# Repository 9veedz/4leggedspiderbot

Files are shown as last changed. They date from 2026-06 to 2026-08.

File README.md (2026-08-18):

# ESP32 Quadruped Spider Robot

> Built largely through vibe coding, iterating with an AI assistant rather than writing every line from scratch. Logic has been tested where possible, but review the code yourself before trusting it on real hardware, especially the servo angle limits.

A 4-legged (12-servo) walking robot controlled by an ESP32, with a built-in WiFi access point and web-based control interface for live tuning, calibration, and gait control — no app required, just a browser.

>  **This project is sponsored by [PCBWay](https://www.pcbway.com)!**

Many thanks to PCBWay for sponsoring this project with high-quality PCBs. As a small hobby project with no real following or funding, being approached by PCBWay for sponsorship genuinely means a lot. I'm truly grateful for the support — it's what made getting real boards in my hands possible. More details in the [sponsor section](#sponsor--pcbway) below.

> ⚠️ This is an ongoing hobby project — still actively being developed and subject to changes.
## Demo

**Walking gait**

Spider Robot Walking (https://youtube.com/shorts/MwilIVm9K1Y)

**Body roll & pitch control**

Spider Robot Body Roll and Pitch (https://youtube.com/shorts/5wvZWfhv1cs)
> The robot moves significantly more fluidly than the videos suggest — the choppy appearance is purely down to the low frame rate of the recording. The inverse kinematics system interpolates each leg smoothly in real time; what you're seeing is a capture artifact, not the actual motion quality.

## Features

- **Inverse kinematics leg control** — each leg independently computes coxa/femur/tibia servo angles from X/Y/Z target positions.
- **Live web UI** — connects directly to the ESP32's own WiFi access point and serves a mobile-friendly control panel over WebSocket (`/ws`) with a captive portal so it opens automatically on connect.
- **Body posture control** — adjustable body height, width, stride length, pitch, and roll, with automatic tilt trim calculation per leg.
- **Walking gaits** — forward and reverse walking gaits using a diagonal-pair stepping pattern (lift → stride → push → recover).
- **Per-leg calibration** — manual servo angle control, configurable min/max safety limits, and offset trims per joint (coxa/femur/tibia), saved persistently to flash (ESP32 NVS/Preferences).
- **Per-leg power control** — individually or globally power legs on/off (releases servo PWM signal) for safe handling or storage.
- **Robot state machine** — `SIT`, `STAND`, `FORWARD`, `REVERSE` states drive automatic transitions between resting and walking behavior.

## Hardware

- ESP32 development board
- PCA9685 16-channel PWM/servo driver (I2C)
- 12x servos (3 per leg: coxa, femur, tibia)
- 4-leg chassis, with legs 1 and 2 mirrored relative to legs 0 and 3
- 3D-printed body: [Thingiverse Thing #2204279](https://www.thingiverse.com/thing:2204279), based on the design from [Instructables: DIY Spider Robot / Quad Robot / Quadruped](https://www.instructables.com/DIY-Spider-RobotQuad-robot-Quadruped/)

> **Important — before assembling the legs onto the 3D-printed body:** power each servo individually and set it to **90 degrees** *before* mounting the horn and locking the leg segments onto the printed body. The codebase has calls toward a `spiderCalibrate()` / `calibrateServos()` path, but it is not a complete, working calibration setup as-is — don't rely on it out of the box. Manually centering each servo to 90° before assembly (e.g. with a basic standalone test sketch) is the safer approach until calibration is properly wired up. The IK math and default offsets (`offC`/`offF`/`offT` = 90) assume each joint's mechanical zero/center point lines up with 90° on the servo. If a horn is attached and the leg geometry locked in at the wrong angle, the leg will be physically offset from where the code thinks it is, and you'll fight it with calibration offsets indefinitely instead of starting from a clean baseline.

| Leg | Coxa Pin | Femur Pin | Tibia Pin | Position | Mirrored |
| --- | --- | --- | --- | --- | --- |
| 0 | 0 | 1 | 2 | Front-left  | No |
| 1 | 3 | 4 | 5 | Front-right | Yes |
| 2 | 6 | 7 | 8 | Back-left | Yes |
| 3 | 9 | 10 | 11 | Back-right  | No |

### Leg Segment Lengths

Each leg has three segments, defined as constants in `SpiderLeg.cpp` and used directly in the inverse kinematics calculations:

| Segment | Joint | Length (mm) | Description |
| --- | ----- | --- | --- |
| L1 | Coxa  | 27.5 | Hip joint offset, rotates leg in X/Y plane |
| L2 | Femur | 55.0 | Upper leg segment |
| L3 | Tibia | 77.5 | Lower leg segment, reaches the ground |

These are physical measurements of the chassis/leg hardware, used by `calculateIK()` to solve for coxa, femur, and tibia joint angles from a target X/Y/Z foot position. If you build this on different hardware, these three constants are the first thing to update to match your own leg dimensions.

## Project Structure

This is an Arduino IDE sketch. Arduino IDE requires a `.ino` file matching the sketch folder name, but all real logic lives in standard `.cpp`/`.h` files, which the IDE compiles automatically alongside it.

```
code/
├── SpiderRobot.ino     # Entry point: setup() / loop()
├── Spider.h / .cpp     # High-level robot behavior: stand, sit, walk, calibrate
├── SpiderLeg.h / .cpp  # Per-leg inverse kinematics & servo output
├── Robotstate.h / .cpp # Shared global state, persistence (flash/NVS)
├── Spiderserver.h / .cpp # WiFi AP, captive portal, WebSocket server
└── Webpage.h           # Embedded HTML/CSS/JS control panel (served from flash)
```

## Code Structure Notes

Each leg is its own object with its own pins and position, and handles its own mirroring internally. `Spider` just tells legs where to go. Makes gait code easier to read, and adding more legs later is mostly just adding more leg objects.

## Getting Started

1. Open `SpiderRobot.ino` in Arduino IDE.
2. Install required libraries via Library Manager:
  - `Adafruit PWM Servo Driver Library`
  - `ESPAsyncWebServer`
  - `AsyncTCP`
  - `ArduinoJson`
  - `DNSServer` (bundled with ESP32 core)
3. Select your ESP32 board under **Tools > Board**.
4. Wire the PCA9685 to the ESP32 via I2C and connect all 12 servos.
5. Flash the sketch.
6. On boot, the ESP32 creates a WiFi access point:
  - **SSID:** `ESP32_Spider`
  - **Password:** `12345678`
7. Connect to that network from a phone or laptop. A captive portal should prompt you to open the control page automatically (or browse to `192.168.4.1` manually).

> **Note:** The AP credentials are currently hardcoded in `Spiderserver.cpp`. Change them before deploying anywhere you don't fully control.

## Using the Web Interface

- **Robot Motion State** — switch between Sit / Stand / Forward / Reverse.
- **Body / Global** — tune body height, width, stride, pitch, and roll in real time.
- **Leg Select & Power** — choose which leg's parameters you're editing, and power individual or all legs on/off.
- **Geometry** — per-leg W/H/L trim offsets.
- **Servo Offsets** — per-joint calibration offsets (coxa/femur/tibia).
- **Servo Angle Control** — manually drive a joint to a specific angle (calibration mode).
- **Servo Min/Max** — set safe angle limits per joint to protect hardware.
- **Save to Flash** — persists all current settings to the ESP32's non-volatile storage.
- **Reload/Reset Defaults** — restores factory default values.

All changes apply live over WebSocket; no page reloads are needed.

## Understanding the Inverse Kinematics

If you want to understand how the leg IK math works before diving into `SpiderLeg.cpp`, this video explains it well:

📺 [Inverse Kinematics for a 3-segment leg — YouTube](https://youtu.be/HjmIOKSp7v4?si=qGuz0ecaw_1wg7XF)

## How to Swap in Your Own Control Scheme

The main robot logic lives in `SpiderLeg`, `Spider`, and `Robotstate` — those are the brains. `Spiderserver` and `Webpage` are just how *this* project talks to the robot over WiFi/WebSocket. You can rip those out entirely and replace them with whatever you want — a Bluetooth remote, an RC receiver, a gamepad, a serial interface — as long as you write to the same variables in `Robotstate`.

Everything the robot responds to is exposed as simple global variables you can read or write from anywhere:

**Body / Posture**

| Variable | Type | Description |
| --- | --- | --- |
| `bodyHeight` | `float` | Overall body height offset |
| `bodyWidth`  | `float` | Overall body width offset |
| `bodyStride` | `float` | Step length used in walking gaits |
| `bodyPitch`  | `float` | Forward/back tilt of the body |
| `bodyRoll` | `float` | Left/right tilt of the body |

**Robot State**

| Variable | Type | Description |
| --- | --- | --- |
| `commandedState` | `RobotStateMode` | What you want the robot to do: `SIT`, `STAND`, `FORWARD`, `REVERSE` |
| `currentState` | `RobotStateMode` | What the robot is currently doing — declared but not yet actively updated separately from `commandedState`, reserved for future state transition logic |
| `activeLeg` | `int` | Which leg (0–3) is selected for tuning |
| `calibrateMode`  | `bool` | ⚠️ Declared but currently unused — reserved for a future calibration mode flow |
| `calibrateLeg` | `int` | ⚠️ Declared but currently unused — intended to track which leg is being calibrated independently of `activeLeg` |

**Computed Per-Leg Arrays** (auto-updated by `updateKinematicArrays()`)

| Variable | Type | Description |
| --- | --- | --- |
| `legHeights[4]` | `float` | Effective height per leg after pitch/roll tilt trim |
| `legWidths[4]`  | `float` | Effective width per leg |

**Per-Leg Parameters** (`legs[0]` through `legs[3]`)

| Field | Type | Description |
| --- | --- | --- |
| `W` | `float` | Manual width trim for this leg |
| `H` | `float` | Manual height trim for this leg |
| `L` | `float` | Lift height used during gait steps |
| `offC / offF / offT` | `float` | Calibration angle offset per joint (coxa/femur/tibia) |
| `servoC / servoF / servoT` | `int` | Raw manual servo angle (used in calibration mode) |
| `cMin/cMax` | `int` | Coxa joint safe angle limits |
| `fMin/fMax` | `int` | Femur joint safe angle limits |
| `tMin/tMax` | `int` | Tibia joint safe angle limits |
| `X / Y / Z` | `float` | ⚠️ Stored and persisted but not yet actively read back into gait logic — reserved for future per-leg position tracking |
| `powerDisabled` | `bool`  | If true, this leg's servos are powered off |

- `Robotstate` holds all shared configuration (body posture, per-leg parameters, current/commanded state) and computes derived kinematic arrays (`legHeights`, `legWidths`) whenever body posture changes, including tilt trim from pitch/roll.
- `SpiderLeg` converts target X/Y/Z leg positions into joint angles via geometric inverse kinematics, then maps those angles to PWM pulses, accounting for whether the leg is mirrored.
- `Spider` orchestrates all four legs together — gait sequencing for walking, synchronized sit/stand/center routines, and calibration mode.
- `Spiderserver` hosts the WiFi AP, captive portal DNS, and WebSocket server, parsing simple text commands (e.g. `bodyHeight=70.0`, `leg=2 offC=85`) from the web UI and broadcasting updated state back to all connected clients.

## PCB

The wiring was getting pretty messy and the space inside the 3D-printed body is quite constrained so the natural next step was to design a proper PCB to clean everything up. Luckily, [PCBWay](https://www.pcbway.com) reached out about a collaboration and sponsored the boards for this project. As a small hobby build with no real following or funding, that was honestly unexpected and really appreciated.

The PCB went through 2 design revisions with a total of 3 boards including a stacked voltage divider board for reading servo positions(under development). Full details, schematics, and board photos are in the PCB folder:

## Sponsor — PCBWay

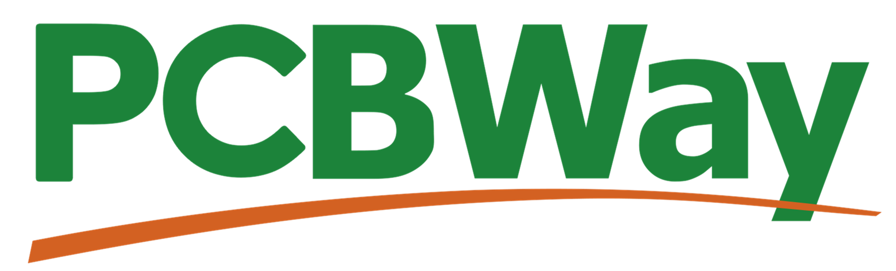
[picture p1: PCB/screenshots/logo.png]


I'm really grateful to **[PCBWay](https://www.pcbway.com)** for sponsoring the PCBs for this project. 
As a hobby engineer doing this on my own time and budget, getting sponsored boards was a massive help and I honestly wasn't expecting the quality to be this good.

### What is PCBWay?

PCBWay is a PCB manufacturer and fab service out of Shenzhen. They do pretty much everything:

- PCB fabrication (single layer all the way up to 20+ layers, rigid, flex, rigid-flex)
- PCB assembly (SMT + through-hole, full turnkey)
- 3D printing (FDM, SLA, SLS, and even metal)
- CNC machining and sheet metal
- One-stop prototyping for small runs

Their online quote tool is instant and the turnaround is genuinely fast standard boards can ship in 24 hours.

---

My Experience

The spiderbot boards aren't super complex but they're not trivial either 12 servo channels, multiple power rails, a stackup between two boards. I uploaded my Gerbers and got a quote almost immediately, no back and forth.

**Ordering was straightforward:**
1. Exported Gerbers and drill files from KiCad and compressed them into a single zip file
2. Uploaded to the PCBWay portal
3. Most of the parameters are selected by default from the gerber files but you can customize according to your requirements
4. Order confirmed and out the door within 24 hours

**When the boards arrived:**
- Well packed anti-static bags inside a solid mailer, no damage
- V-score lines on the panel were clean and snapped apart easily
- Soldermask was crisp, silkscreen was readable, no bridging on any pads

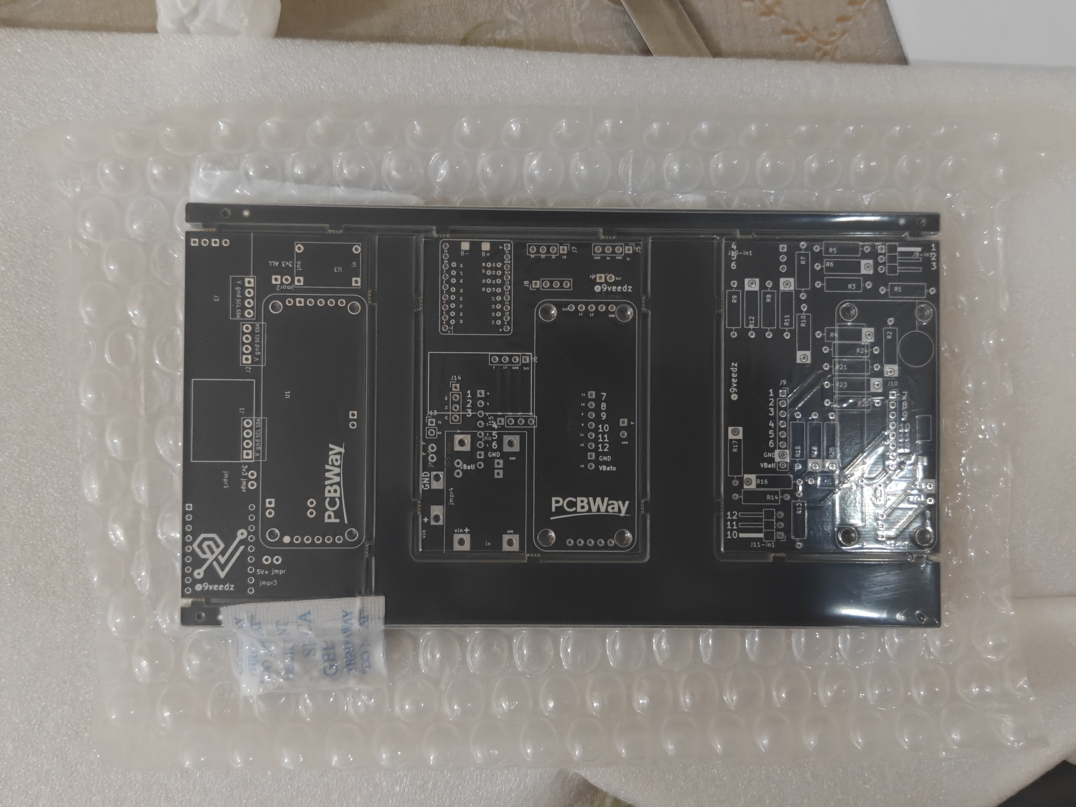
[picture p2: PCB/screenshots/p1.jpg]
Packaging


**Received Boards**

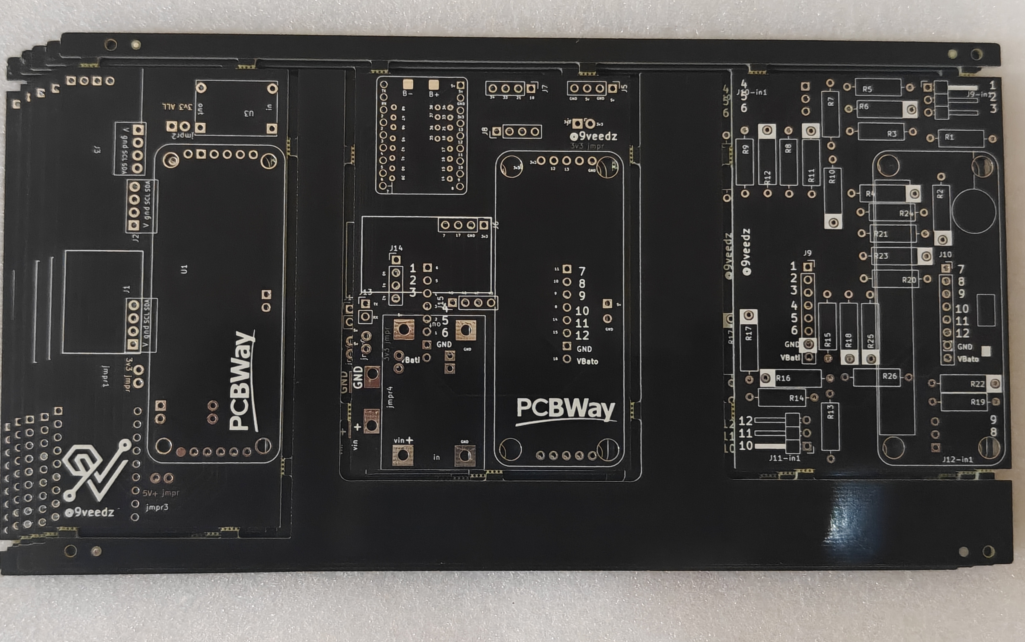
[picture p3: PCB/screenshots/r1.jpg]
PCB Received 1


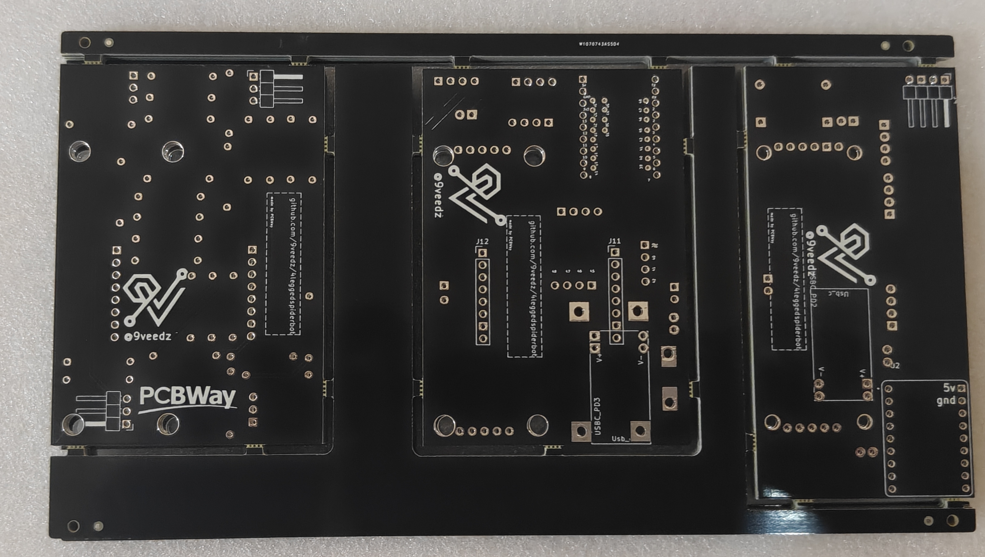
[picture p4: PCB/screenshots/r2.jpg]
PCB Received 2


**Dimensions held up:**
- Outline matched my design within ±0.1mm
- Vias and traces exactly as in the Gerbers
- Stacking fit between the two boards was spot on

Honestly for a hobby project like this, PCBWay hit the sweet spot of quality, speed, and price. If you're building something similar definitely worth checking them out → [pcbway.com](https://www.pcbway.com)

→ [PCB README — designs, components, and build notes](PCB/readme(2).md)

## Future Notes

Planned / possible extensions, made straightforward by the existing modular structure:

- **More walking patterns** — turning (left/right), crab walk (lateral movement using the existing `crab()` primitive in `SpiderLeg`), and a dance routine are planned. The gait system is structured as a phase/substep state machine in `Spider.cpp`, so new patterns slot in as additional `walkX()` methods without touching the leg kinematics.
- **IMU-based balancing** — add an IMU (e.g. MPU6050) and feed pitch/roll readings into a PID loop that continuously adjusts `bodyPitch`/`bodyRoll` (or per-leg height directly) to keep the body level on uneven terrain. Since `updateKinematicArrays()` already recalculates per-leg height/width trim from `bodyPitch`/`bodyRoll` via `calculateTiltTrim()`, this mostly means replacing manual slider input with a PID controller's output on the same variables — no kinematics rewrite needed.
- **Remote control input** — because all robot control already flows through simple state changes (`commandedState`, `bodyHeight`, `bodyWidth`, etc. in `Robotstate`) rather than being tightly coupled to the WebSocket parser, an RC receiver, Bluetooth gamepad, or other remote input method can be added as just another input source writing to those same variables, alongside or instead of the web UI.

The decoupled design (state in `Robotstate`, kinematics in `SpiderLeg`, orchestration in `Spider`, I/O in `Spiderserver`) means new input/sensor sources generally plug into the *existing* state variables rather than requiring changes to gait logic or IK code.

## License

CC BY-NC-SA 4.0 (Attribution-NonCommercial-ShareAlike) — see [LICENSE](LICENSE) for details. Free for personal/non-commercial use and modification with credit to `9veedz`; selling this project or derivatives of it is not permitted.

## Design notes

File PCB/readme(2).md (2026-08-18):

# 4-Legged Spiderbot — PCB

So this is the PCB folder for my spiderbot project a 4-legged walking robot I've been building in my spare time. It's been a fun (and sometimes painful) journey getting here.

---

## PCB Designs

I went through 2 design revisions and ended up with 3 boards total. Here's how it went:

---

### Design 1 Single MCU Board

My first attempt everything on one board. Kept it simple.

| Component | Role |
|---|---|
| ESP32-S3 Supermini | Main MCU — hosts a WiFi HTML control page |
| PCA9685 | 16-channel PWM driver — drives all 12 servos |
| Buck step-down converter | Steps down input voltage to power the logic and servos |
| USB-C PD trigger board | Triggers USB-PD to get the right voltage into the buck |
| MPU-6050 | 6-axis IMU for orientation and tilt sensing |
| Output filter capacitors | Clean up the buck output |
| Header pins | Connections and module mounting |

Also broke out multiple I2C ports on separate pins makes it easy to chain extra sensors or modules without fighting over the same lines.

The robot gets controlled through a webpage the ESP32-S3 hosts over WiFi. the phone does all the heavy lifting (IK, gait logic) and sends commands down to the PCA9685 which then drives the servos.

**Front**

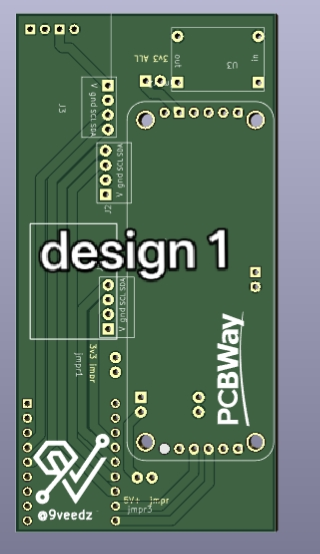
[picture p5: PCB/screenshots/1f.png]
Design 1 MCU Board Front


**Back**

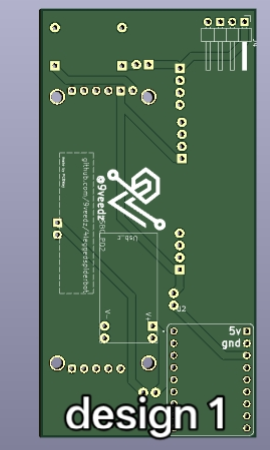
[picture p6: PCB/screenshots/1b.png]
Design 1 MCU Board Back


---

### Design 2 MCU Board + Voltage Divider Stackup (2 Boards)

After getting Design 1 working I wanted to add proper servo position feedback so I split it into two stacked boards. Also upgraded the power side since the servos were pulling more current than I expected.

**Board 1 MCU Board**

Pretty much the same as Design 1 but with a beefier buck:

| Component | Role |
|---|---|
| ESP32-S3 Supermini | Main MCU WiFi control page |
| PCA9685 | 16-channel PWM driver all 12 servos |
| 5V 8A buck converter | Much beefier this time takes battery input directly, 5V @ 8A for the servos |
| MPU-6050 | 6-axis IMU |
| Header pins | Interface to the voltage divider board stacked on top |

Also in this revision I mapped out all the GPIOs to header pins so if I want to hook up extra peripherals, sensors, or expand the project later, the pins are already there and accessible without any rework.

**Board 2 Voltage Divider Board** (stacks on top of Board 1)

This little board stacks right below the mcu and reads servo positions by tapping into each servo's internal pot:

| Component | Role |
|---|---|
| Resistor voltage dividers | One per servo scales the pot signal down to a safe ADC input range |
| Resistor voltage divider | Battery level monitoring |
| Header pins | Connects down to Board 1 and feeds signals into the ESP32-S3 ADC pins |

The idea is to tap into the servo's internal position potentiometer and use that as feedback for closed-loop position control. Pretty cool once it works!

**Front**

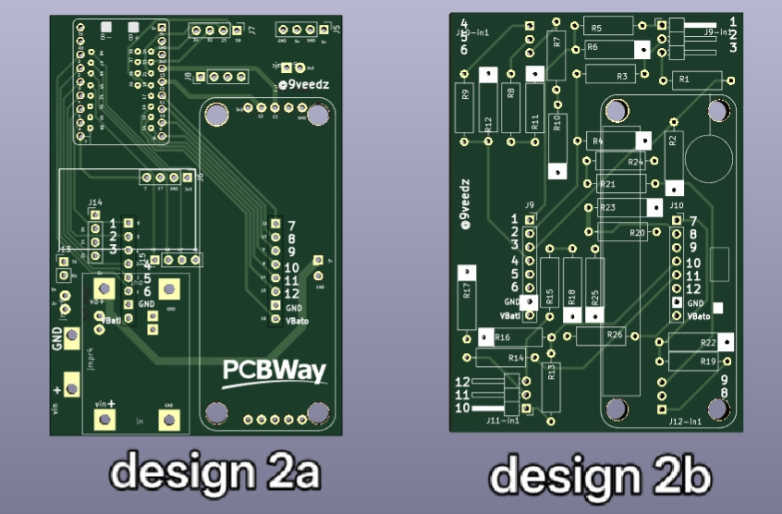
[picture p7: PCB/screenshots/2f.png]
Design 2 MCU Board + Voltage Divider Stackup Front


**Back**

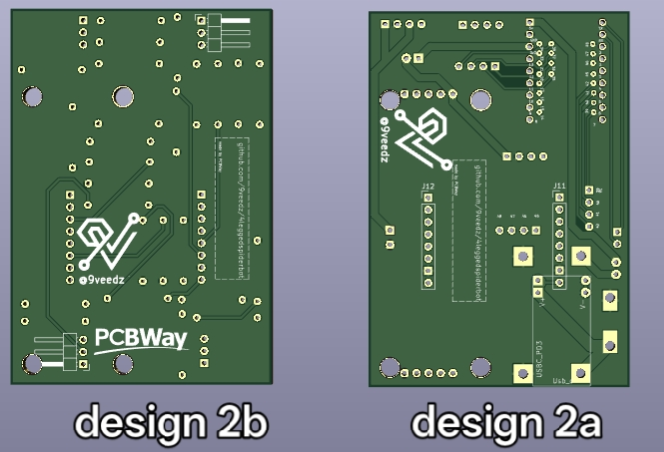
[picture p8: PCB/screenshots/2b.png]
Design 2 MCU Board + Voltage Divider Stackup Back


---

## Repo

Full project: [github.com/9veedz/4leggedspiderbot](https://github.com/9veedz/4leggedspiderbot)

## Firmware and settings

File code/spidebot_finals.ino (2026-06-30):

#include <Arduino.h>
#include <Wire.h>
#include <Adafruit_PWMServoDriver.h>
#include "Robotstate.h"
#include "Spider.h"
#include "Spiderserver.h"

// Defined exactly once, here. Declared extern in SpiderLeg.h.
Adafruit_PWMServoDriver pwm = Adafruit_PWMServoDriver(0x40);

Spider spider;

void setup() {
  Serial.begin(115200);

  // I2C on custom pins: SDA=8, SCL=9
  Wire.begin(7, 6);

  pwm.begin();
  pwm.setPWMFreq(50); // standard analog servo frequency

  robotStateLoad();

  spider.begin();

  spiderServerBegin();
}

void loop() {
  spiderServerLoop();

  if (commandedState == FORWARD) {
    spider.walkForward();
  } else if (commandedState == REVERSE) {
    spider.walkReverse();
  } else if (commandedState == STAND) {
    spider.stand();
  } else if (commandedState == SIT) {
    spider.sit();
  }

  spider.updateAll();
}

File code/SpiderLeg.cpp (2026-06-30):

#include "SpiderLeg.h"

SpiderLeg::SpiderLeg(int cp, int fp, int tp, int id)
    : cPin(cp), fPin(fp), tPin(tp), legId(id) {
  
  // Rule mapping: Legs 1 and 2 are on the mirrored side of the chassis
  mirrored = (legId == 1 || legId == 2);

  curX = tarX = 0.0;
  curY = tarY = 0.0;
  curZ = tarZ = 0.0;
}

void SpiderLeg::setX(float x) { tarX = legWidths[legId] + x; }
void SpiderLeg::setY(float y) { tarY = mirrored ? -(y + 20) : (y + 20); }
void SpiderLeg::setZ(float z) { tarZ = -legHeights[legId] + z; }

void SpiderLeg::setTarget(float x, float y, float z) {
  setX(x); setY(y); setZ(z);
}


void SpiderLeg::calibrateServos() {
  // 1. Pull raw manual angles directly from Web UI sliders (0 to 180)
  float targetC = legs[legId].servoC;
  float targetF = legs[legId].servoF;
  float targetT = legs[legId].servoT;

  // 2. Pull min/max safety limits live from the global configuration
  int cMin = legs[legId].cMin, cMax = legs[legId].cMax;
  int fMin = legs[legId].fMin, fMax = legs[legId].fMax;
  int tMin = legs[legId].tMin, tMax = legs[legId].tMax;

  // 3. Clamp raw slider inputs directly to safety limits (No offsets applied)
  float outC = constrain(targetC, cMin, cMax);
  float outF = constrain(targetF, fMin, fMax);
  float outT = constrain(targetT, tMin, tMax);

  // 4. Write directly to PCA9685 using your physical chassis orientation mapping
  if (mirrored) {
    pwm.setPWM(cPin, 0, map(outC, 0, 180, 600, 150));
    pwm.setPWM(fPin, 0, map(outF, 0, 180, 150, 600));
    pwm.setPWM(tPin, 0, map(outT, 0, 180, 150, 600));
  } else {
    pwm.setPWM(cPin, 0, map(outC, 0, 180, 150, 600));
    pwm.setPWM(fPin, 0, map(outF, 0, 180, 600, 150));
    pwm.setPWM(tPin, 0, map(outT, 0, 180, 600, 150));
  }
}

void SpiderLeg::calculateIK(float x, float y, float z) {
  if (x == 0)
    x = 0.01;
  angC = atan2(y, x) * 180.0 / PI;
  float R = sqrt(x * x + y * y) - L1;
  float D_dist = sqrt(R * R + z * z);
  float cos_t = (pow(L2, 2) + pow(L3, 2) - pow(D_dist, 2)) / (2 * L2 * L3);
  angT = acos(constrain(cos_t, -1, 1)) * 180.0 / PI;
  float alpha = atan2(z, R);
  float cos_f = (pow(L2, 2) + pow(D_dist, 2) - pow(L3, 2)) / (2 * L2 * D_dist);
  angF = (alpha + acos(constrain(cos_f, -1, 1))) * 180.0 / PI;
}

void SpiderLeg::updatePosition() {
  // Accuracy window changed to 1 for physical servo stability
   if (legs[legId].powerDisabled) return;
   
  if (abs(tarX - curX) > 1)
    curX += (tarX > curX) ? stepSize : -stepSize;
  if (abs(tarY - curY) > 1)
    curY += (tarY > curY) ? stepSize : -stepSize;
  if (abs(tarZ - curZ) > 1)
    curZ += (tarZ > curZ) ? stepSize : -stepSize;

  float ikY = mirrored ? -curY : curY;  // Flip Y into IK for mirrored legs
  calculateIK(curX, ikY, curZ);

  // Pull calibration offsets live from the global shared structure array
  float liveOffC = legs[legId].offC;
  float liveOffF = legs[legId].offF;
  float liveOffT = legs[legId].offT;

  // Pull min/max safety limits live from the same structure
  int cMin = legs[legId].cMin, cMax = legs[legId].cMax;
  int fMin = legs[legId].fMin, fMax = legs[legId].fMax;
  int tMin = legs[legId].tMin, tMax = legs[legId].tMax;

  // Clamp final (angle + offset) result to each joint's configured safe range
  // before it's ever mapped to a PWM pulse.
  float outC = constrain(angC + liveOffC, cMin, cMax);
  float outF = constrain(angF + liveOffF, fMin, fMax);
  float outT = constrain(90 - angT + liveOffT, tMin, tMax);

  if (mirrored) {
    pwm.setPWM(cPin, 0, map(outC, 0, 180, 600, 150));
    pwm.setPWM(fPin, 0, map(outF, 0, 180, 150, 600));
    pwm.setPWM(tPin, 0, map(outT, 0, 180, 150, 600));
  } else {
    pwm.setPWM(cPin, 0, map(outC, 0, 180, 150, 600));
    pwm.setPWM(fPin, 0, map(outF, 0, 180, 600, 150));
    pwm.setPWM(tPin, 0, map(outT, 0, 180, 600, 150));
  }
}

void SpiderLeg::legOff() {
    legs[legId].powerDisabled = true; // Enable the lockout
    // Force PCA9685 channels to full off
    pwm.setPWM(cPin, 4096, 0);
    pwm.setPWM(fPin, 4096, 0);
    pwm.setPWM(tPin, 4096, 0);
}
void SpiderLeg::legOn() {
    legs[legId].powerDisabled = false; // Disable the lockout
    updatePosition();      // Resume normal position calculations and PWM
}

bool SpiderLeg::isMoving() {
  return (abs(tarX - curX) > 2.0 || 
          abs(tarZ - curZ) > 2.0 || 
          abs(tarY - curY) > 2.0);
}

void SpiderLeg::lift(float L)            { setZ(L); }              // raw Z, Y untouched
void SpiderLeg::down()                   { setZ(-5); }
void SpiderLeg::strideF(float strideY)   { setY(strideY); }        // raw Y, Z untouched
void SpiderLeg::home()                 { setTarget(0, 0, 0); }            // Y untouched — matches your doc
void SpiderLeg::crab(float strideX)      { setX(strideX); }

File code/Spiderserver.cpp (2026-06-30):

#include "Spiderserver.h"
#include "Robotstate.h"
#include <WiFi.h>
#include <DNSServer.h>
#include <AsyncTCP.h>
#include <ESPAsyncWebServer.h>
#include <ArduinoJson.h>
#include "Webpage.h"

// Instantiate server on port 80 and websocket at route /ws
AsyncWebServer server(80);
AsyncWebSocket ws("/ws");

// DNS Server instance to handle Captive Portal interception
DNSServer dnsServer;
const byte DNS_PORT = 53;

// Serializes and pushes the complete live robot state down the websocket
void sendRobotStateSnapshot(uint32_t clientId) {
  JsonDocument doc;

  // Global Body Configs
  doc["bH"] = bodyHeight;
  doc["bW"] = bodyWidth;
  doc["bS"] = bodyStride;
  doc["bP"] = bodyPitch;
  doc["bR"] = bodyRoll;
  doc["aL"] = activeLeg;
  doc["cSt"] = (int)commandedState;

  // Active Leg Configurations
  JsonObject legObj = doc["leg"].to<JsonObject>();
  legObj["W"]     = legs[activeLeg].W;
  legObj["H"]     = legs[activeLeg].H;
  legObj["L"]     = legs[activeLeg].L;
  legObj["offC"]  = legs[activeLeg].offC;
  legObj["offF"]  = legs[activeLeg].offF;
  legObj["offT"]  = legs[activeLeg].offT;
  legObj["servoC"]= legs[activeLeg].servoC;
  legObj["servoF"]= legs[activeLeg].servoF;
  legObj["servoT"]= legs[activeLeg].servoT;
  legObj["X"]     = legs[activeLeg].X;
  legObj["Y"]     = legs[activeLeg].Y;
  legObj["Z"]     = legs[activeLeg].Z;

  legObj["cMin"]  = legs[activeLeg].cMin;
  legObj["cMax"]  = legs[activeLeg].cMax;
  legObj["fMin"]  = legs[activeLeg].fMin;
  legObj["fMax"]  = legs[activeLeg].fMax;
  legObj["tMin"]  = legs[activeLeg].tMin;
  legObj["tMax"]  = legs[activeLeg].tMax;

  legObj["enabled"] = !legs[activeLeg].powerDisabled;

  String jsonString;
  serializeJson(doc, jsonString);

  // Transmit initialization payload directly to the connecting client
  ws.text(clientId, jsonString);
}

// Intercepts and processes incoming payloads from the Web UI / WebSocket channel
void onWebSocketEvent(AsyncWebSocket *server, AsyncWebSocketClient *client, AwsEventType type, void *arg, uint8_t *data, size_t len) {
  if (type == WS_EVT_CONNECT) {
    Serial.printf("[WS] client #%u connected from %s\n", (unsigned int)client->id(), client->remoteIP().toString().c_str());

    // Trigger two-way bidirectional handshake instantly upon WebSocket connection
    sendRobotStateSnapshot(client->id());
  }
  else if (type == WS_EVT_DISCONNECT) {
    Serial.printf("[WS] client #%u disconnected\n", (unsigned int)client->id());
  }
  else if (type == WS_EVT_DATA) {
    AwsFrameInfo *info = (AwsFrameInfo*)arg;
    if (info->final && info->index == 0 && info->opcode == WS_TEXT) {
      data[len] = 0;
      String msg = (char*)data;
      msg.trim();

      Serial.printf("[WS] received: %s\n", msg.c_str());

      // Parse commands (e.g., "state=sit", "leg=0", "bodyHeight=70.0", etc.)
      if (msg.startsWith("save")) {
        robotStateSave();
        Serial.println("[State] saved to flash");
      }
      // RESET command: Pulls configurations from NVS and pushes the state back out
      else if (msg.startsWith("reset")) {
        robotStateResetDefaults(); // Overwrites RAM with factory defaults
        Serial.println("[State] reset to factory defaults");

        // Push the refreshed variables back to all connected WebSockets clients
        for (AsyncWebSocketClient &c : ws.getClients()) {
          if (c.status() == WS_CONNECTED) {
            sendRobotStateSnapshot(c.id());
          }
        }
      }
      else if (msg.startsWith("state=")) {
        String stateStr = msg.substring(6);
        stateStr.toLowerCase();

        if (stateStr == "sit") {
          commandedState = SIT;
        } else if (stateStr == "stand") {
          commandedState = STAND;
        } else if (stateStr == "forward") {
          commandedState = FORWARD;
        } else if (stateStr == "reverse") {
          commandedState = REVERSE;
        }
      }
      else if (msg.startsWith("leg=") && msg.indexOf(' ') == -1) {
        activeLeg = msg.substring(4).toInt();
        if (activeLeg < 0) activeLeg = 0;
        if (activeLeg > 3) activeLeg = 3;
        Serial.printf("[WS] leg select -> %d\n", activeLeg);
      }
      // Global values parsing with kinematic updates & broadcast sync
      else if (msg.startsWith("bodyHeight=")) {
        bodyHeight = msg.substring(11).toFloat();
        updateKinematicArrays();
        for (AsyncWebSocketClient &c : ws.getClients()) {
          if (c.status() == WS_CONNECTED) sendRobotStateSnapshot(c.id());
        }
        Serial.printf("[WS] bodyHeight=%.2f\n", bodyHeight);
      }
      else if (msg.startsWith("bodyWidth=")) {
        bodyWidth = msg.substring(10).toFloat();
        updateKinematicArrays();
        for (AsyncWebSocketClient &c : ws.getClients()) {
          if (c.status() == WS_CONNECTED) sendRobotStateSnapshot(c.id());
        }
        Serial.printf("[WS] bodyWidth=%.2f\n", bodyWidth);
      }
      else if (msg.startsWith("bodyStride=")) {
        bodyStride = msg.substring(11).toFloat();
        Serial.printf("[WS] bodyStride=%.2f\n", bodyStride);
      }
      else if (msg.startsWith("bodyPitch=")) {
        bodyPitch = msg.substring(10).toFloat();
        updateKinematicArrays();
        for (AsyncWebSocketClient &c : ws.getClients()) {
          if (c.status() == WS_CONNECTED) sendRobotStateSnapshot(c.id());
        }
        Serial.printf("[WS] bodyPitch=%.2f\n", bodyPitch);
      }
      else if (msg.startsWith("bodyRoll=")) {
        bodyRoll = msg.substring(9).toFloat();
        updateKinematicArrays();
        for (AsyncWebSocketClient &c : ws.getClients()) {
          if (c.status() == WS_CONNECTED) sendRobotStateSnapshot(c.id());
        }
        Serial.printf("[WS] bodyRoll=%.2f\n", bodyRoll);
      }
      // All-legs broadcast (e.g. "leg=all enabled=0")
      else if (msg.startsWith("leg=all")) {
        int spaceIdx = msg.indexOf(' ');
        if (spaceIdx != -1) {
          String paramPair = msg.substring(spaceIdx + 1);
          int eqIdx = paramPair.indexOf('=');
          if (eqIdx != -1) {
            String pKey = paramPair.substring(0, eqIdx);
            float pVal = paramPair.substring(eqIdx + 1).toFloat();

            if (pKey == "enabled") {
              bool isEnabled = (pVal != 0);
              for (int i = 0; i < 4; i++) {
                legs[i].powerDisabled = !isEnabled;
              }
              Serial.printf("[WS] all legs enabled=%d\n", isEnabled);
            }
          }
        }
      }
      // Per-leg parameters mapping (e.g. "leg=0 W=70")
      else if (msg.startsWith("leg=")) {
        int legIdx = msg.substring(4, 5).toInt();
        int spaceIdx = msg.indexOf(' ');

        if (legIdx >= 0 && legIdx <= 3 && spaceIdx != -1) {
          String paramPair = msg.substring(spaceIdx + 1);
          int eqIdx = paramPair.indexOf('=');

          if (eqIdx != -1) {
            String pKey = paramPair.substring(0, eqIdx);
            float pVal = paramPair.substring(eqIdx + 1).toFloat();
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
